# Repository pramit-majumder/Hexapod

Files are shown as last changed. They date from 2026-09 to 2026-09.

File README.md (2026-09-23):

# Custom 18-DOF Hexapod Robot






A custom-built 18-DOF hexapod robot developed as an undergraduate robotics project by Pramit Majumder, Mechatronics Engineering, KIIT. The project integrates mechanical design, servo control, inverse kinematics, ROS 2, gait generation, and real-world locomotion.

The robot is being developed as a complete hardware–software robotics system, covering mechanical construction, electronics, embedded control, kinematics, trajectory generation, and physical testing.

## Project Status

The project is currently under development. Mechanical assembly, servo and electronics testing, ROS 2 control architecture, inverse kinematics, and gait generation are being developed in parallel. Full-body locomotion testing is planned after the mechanical, electrical, and control subsystems have been validated.

## Robot Overview

The robot has six independently controlled legs. Each leg contains three actuated joints:

- Coxa.
- Femur.
- Tibia.

The total number of degrees of freedom is:

\[
6\text{ legs} \times 3\text{ DOF per leg}=18\text{ DOF}
\]

Each leg is modeled as a 3-DOF serial manipulator, allowing the foot position to be controlled in three-dimensional space.

### Approximate Leg Dimensions

| Link | Length |
|---|---:|
| Coxa | 50 mm |
| Femur | 75 mm |
| Tibia | 112 mm |

The approximate coxa–femur–tibia proportion is 0.67:1:1.5.

## Hardware

### Actuation

- 18 × MG995 servo motors.
- Three servo motors per leg.
- PCA9685 PWM servo drivers.

### Main Controllers

- Arduino Mega for low-level servo control.
- Raspberry Pi 4B for higher-level computation and robot control.

### Additional Hardware

- Custom and 3D-printed ABS structural components.
- Hexagonal top and base plates.
- Bearings for selected joints.
- M3 and M4 mechanical fasteners.
- External servo power supply.
- ESP32-CAM for future perception and scouting functionality.

The servo power system is electrically separated from the logic and control electronics. A common ground must be maintained between the servo supply, PCA9685 boards, Arduino, and communication interface.

## Software Architecture

The software stack is divided into high-level computation and low-level actuation layers:

```text
                         ROS 2
                           |
              +------------+------------+
              |                         |
       Waypoint Generator              IK
              |                         |
              +------------+------------+
                           |
                      Leg Control
                           |
                    Serial / MCU Link
                           |
                    Arduino Mega
                           |
                         I2C
                           |
                       PCA9685
                           |
                    18 Servo Motors
```

High-level motion commands are separated from the low-level servo implementation. This allows the kinematics, gait, and planning layers to operate using Cartesian or joint-space commands without depending directly on the servo driver implementation.

## ROS 2 Packages

### `hexapod_interfaces`

Custom ROS 2 interfaces used for communication among the robot's software components.

#### `Coordinates`

Represents a desired Cartesian foot position and the associated leg geometry:

```text
int64 x
int64 y
int64 z

int64 coxa_length
int64 femur_length
int64 tibia_length

float32 coxa
float32 femur
float32 tibia
```

The coordinate and geometry fields may be refactored into separate messages as the interface matures, so that input geometry and calculated joint angles are represented more clearly.

#### `LegActuators`

Transmits calculated joint actuator positions to the low-level controller. The message is intended to carry mapped actuator commands after servo offsets, direction inversions, and leg-specific calibration have been applied.

### `leg_control`

The `leg_control` node converts joint commands into actuator commands and communicates with the microcontroller through a serial connection.

### `waypoint_generator`

The waypoint-generation node produces discrete Cartesian foot positions for individual legs and coordinated gait execution.

## Communication Architecture

The robot uses a layered communication system:

- Serial communication for the Raspberry Pi–Arduino control link.
- I2C communication between the Arduino and PCA9685 PWM drivers.
- PWM signals from the PCA9685 boards to the servo motors.

The communication layer should include command validation, timeout handling, range checks, and a safe output state when the connection is interrupted.

## Motion Pipeline

The intended motion pipeline is:

```text
Desired Motion
      |
      v
Waypoints
      |
      v
Foot Coordinates
      |
      v
Inverse Kinematics
      |
      v
Joint Angles
      |
      v
Servo Mapping
      |
      v
Servo Commands
      |
      v
Physical Robot
```

## Kinematics

Each leg is modeled as a 3-DOF serial manipulator consisting of:

- Coxa joint.
- Femur joint.
- Tibia joint.

The inverse kinematics (IK) system calculates the three joint angles required to place the foot at a desired Cartesian position:

\[
P=(x,y,z)
\]

where \(x\), \(y\), and \(z\) represent the desired foot position relative to the leg coordinate frame.

The coxa joint primarily rotates the leg about the vertical axis, while the femur and tibia joints control the foot position in the resulting vertical plane.

### Leg Parameters

The current physical leg dimensions are:

\[
L_c=50\text{ mm},\qquad L_f=75\text{ mm},\qquad L_t=112\text{ mm}
\]

where:

- \(L_c\) is the coxa length.
- \(L_f\) is the femur length.
- \(L_t\) is the tibia length.

The equations below assume a defined leg coordinate convention in which the coxa angle is measured using `atan2(y, x)`, and the femur–tibia plane uses the reduced horizontal distance and signed vertical coordinate. Servo mounting conventions may require angle offsets, sign changes, or alternate elbow configurations.

### Coxa Angle

The coxa joint determines the horizontal rotation of the leg around the vertical axis:

\[
\boxed{\theta_c=\operatorname{atan2}(y,x)}
\]

### Horizontal Distance

The horizontal distance from the coxa joint to the foot is:

\[
r=\sqrt{x^2+y^2}
\]

After removing the coxa link length, the effective horizontal distance for the femur–tibia plane is:

\[
\boxed{r'=r-L_c}
\]

or, equivalently:

\[
\boxed{r'=\sqrt{x^2+y^2}-L_c}
\]

### Femur–Tibia Distance

The distance between the femur joint and the desired foot position is:

\[
\boxed{D=\sqrt{r'^2+z^2}}
\]

### Tibia Angle

Using the law of cosines, the internal femur–tibia angle is:

\[
\boxed{\theta_t=\cos^{-1}\left(\frac{L_f^2+L_t^2-D^2}{2L_fL_t}\right)}
\]

The servo command for the tibia is obtained from this geometric angle using the selected physical mounting convention. For example, an actuated knee may require \(\pi-\theta_t\), a sign inversion, or an offset.

### Femur Angle

First, calculate the angle between the horizontal axis and the line connecting the femur joint to the foot:

\[
\alpha=\operatorname{atan2}(z,r')
\]

The internal angle between the femur link and the line connecting the femur joint to the foot is:

\[
\beta=\cos^{-1}\left(\frac{L_f^2+D^2-L_t^2}{2L_fD}\right)
\]

For the selected branch of the IK solution, the femur angle is:

\[
\boxed{\theta_f=\operatorname{atan2}(z,r')+\cos^{-1}\left(\frac{L_f^2+D^2-L_t^2}{2L_fD}\right)}
\]

The alternate elbow configuration can be obtained by changing the sign of the triangle term. The final branch must be selected according to the physical leg geometry, desired posture, joint limits, and collision constraints.

### Complete IK Formulation

The complete inverse kinematics calculation is summarized as:

\[
\boxed{\theta_c=\operatorname{atan2}(y,x)}
\]

\[
\boxed{r'=\sqrt{x^2+y^2}-L_c}
\]

\[
\boxed{D=\sqrt{r'^2+z^2}}
\]

\[
\boxed{\theta_t=\cos^{-1}\left(\frac{L_f^2+L_t^2-D^2}{2L_fL_t}\right)}
\]

\[
\boxed{\theta_f=\operatorname{atan2}(z,r')+\cos^{-1}\left(\frac{L_f^2+D^2-L_t^2}{2L_fD}\right)}
\]

The resulting geometric joint-angle vector is:

\[
\boxed{(\theta_c,\theta_f,\theta_t)}
\]

These geometric angles are subsequently converted into servo commands. Servo offsets, direction inversions, left/right leg mirroring, calibration limits, and mounting orientation are handled separately according to the physical configuration of each leg.

Before evaluating the inverse trigonometric functions in software, the cosine arguments should be clamped to the interval \([-1,1]\) to protect against floating-point rounding errors.

### Reachability

A requested foot position is reachable only when the femur–tibia distance satisfies:

\[
\boxed{|L_f-L_t|\le D\le L_f+L_t}
\]

For the current leg dimensions:

\[
\boxed{37\text{ mm}\le D\le187\text{ mm}}
\]

Positions outside this workspace cannot be reached by the femur–tibia pair using the current link geometry. In practice, the usable workspace is smaller because of servo limits, mechanical interference, structural deflection, cable routing, and collision avoidance.

The geometric reachability check should be performed before calculating the inverse trigonometric terms. A complete implementation should also check the coxa angle range, femur and tibia servo limits, and whether the resulting configuration causes self-collision or ground contact.

### Coordinate-to-Actuator Pipeline

```text
Desired Foot Position
          |
          v
       (x, y, z)
          |
          v
  Reachability and Limits Check
          |
          v
    Inverse Kinematics
          |
          +----> Coxa Angle
          |
          +----> Femur Angle
          |
          +----> Tibia Angle
          |
          v
  Servo Mapping / Calibration
          |
          v
    PCA9685 PWM Commands
          |
          v
        Servos
```

## Motion Generation

The robot is intended to support both individual leg motion and coordinated six-leg locomotion. Development proceeds through the following stages:

1. Individual servo testing.
2. Individual leg movement.
3. Full-leg synchronization.
4. Cartesian foot positioning.
5. Waypoint generation.
6. Gait generation.
7. Coordinated leg movement.
8. Full-body locomotion testing.

The project distinguishes between point-to-point movement and continuous trajectories. Point-to-point motion commands a leg or joint between defined positions, whereas trajectory-based motion generates intermediate states over time to provide smoother motion and better control of velocity and acceleration.

## Gait Development

The gait system will coordinate:

- Leg lifting.
- Foot placement.
- Swing and stance phases.
- Body support.
- Foot trajectories.
- Inter-leg timing.
- Stability during weight transfer.

The gait generator will provide target foot positions to the inverse kinematics layer rather than directly commanding servo motors.

```text
Gait Generator
      |
      v
Foot Trajectory
      |
      v
Cartesian Coordinates
      |
      v
Inverse Kinematics
      |
      v
Joint Angles
      |
      v
Servo Controller
```

## Mechanical Design

The mechanical structure is designed and fabricated using 3D-printed components. Current printed parts use ABS filament with approximately 15% infill.

The mechanical design prioritizes:

- Low mass.
- Sufficient joint strength.
- Simple assembly.
- Replaceable components.
- Accessible electronics.
- Practical servo mounting.

Bearings are used at selected mechanical joints to reduce friction and mechanical loading. Final structural validation should account for servo torque, impact loads, printed-part anisotropy, fastener pull-out, and deflection under static and dynamic conditions.

## Electronics

The basic servo-control architecture is:

```text
ROS 2 / Raspberry Pi
          |
        Serial
          |
    Arduino Mega
          |
          I2C
          |
       PCA9685
          |
    18 Servo Motors
```

The PCA9685 provides dedicated PWM channels, allowing the Arduino to control the robot's servos without requiring one hardware PWM output per servo. The Arduino handles low-level timing and actuator commands, while the Raspberry Pi performs higher-level computation, kinematics, waypoint generation, and gait control.

The power system should be designed for the high instantaneous current demand of 18 MG995 servos. Logic power and servo power should use appropriate regulation, wiring, fusing, connectors, and a common ground. Emergency stop and staged power-up procedures are recommended during testing.

## Development Environment

### Robotics

- ROS 2.
- Ubuntu 22.04.
- Python.
- C++.
- Arduino.
- Raspberry Pi.

The project focuses on direct physical robot development, embedded control, ROS 2 integration, and hardware validation.

## Planned Learning-Based Control

A future direction is the investigation of neural-network-based robot control. Potential applications include:

- Neural-network inverse kinematics.
- Learned foot-position mapping.
- Reinforcement-learning-based gait generation.
- Sim-to-real policy transfer.

The learning-based controller is intended to complement, rather than replace, the conventional robot model and control pipeline. Analytical kinematics, joint limits, safety checks, and low-level actuator protections should remain available as a reliable baseline and safety layer.

## Development Roadmap

1. Design the hexapod structure.
2. Design the individual leg geometry.
3. Manufacture the initial mechanical components.
4. Assemble and validate one leg.
5. Test individual servos.
6. Establish PCA9685 servo control.
7. Complete the mechanical assembly.
8. Complete and validate the power system.
9. Finalize the top plate.
10. Test all 18 actuators.
11. Implement and validate inverse kinematics.
12. Implement waypoint generation.
13. Research and select a gait.
14. Implement gait generation.
15. Test coordinated leg movement.
16. Test complete robot locomotion.
17. Develop a learning-based controller.
18. Investigate sim-to-real transfer.

## Repository Structure

```text
hexapod/
├── README.md
├── ros2_ws/
│   └── src/
│       ├── hexapod_interfaces/
│       ├── leg_control/
│       └── waypoint_generator/
├── firmware/
│   └── arduino/
├── kinematics/
├── gait/
├── CAD/
├── documentation/
└── tests/
```

The repository structure may change as the project develops.

## Project Goals

The primary goal is to develop a complete custom hexapod platform rather than simply assemble a commercially available robot. The project combines:

- Mechanical design.
- Embedded systems.
- Robotics control.
- Forward and inverse kinematics.
- Motion planning.
- Gait generation.
- ROS 2 integration.
- Computer vision.
- Machine learning.

The final system is intended to provide a platform for experimenting with conventional and learning-based approaches to legged robotics.

## License

The project is intended to be released under the MIT License. The license status should be finalized when the repository is published.

## Author

**Pramit Majumder**  
Mechatronics Engineering  
KIIT  
Undergraduate Robotics Project

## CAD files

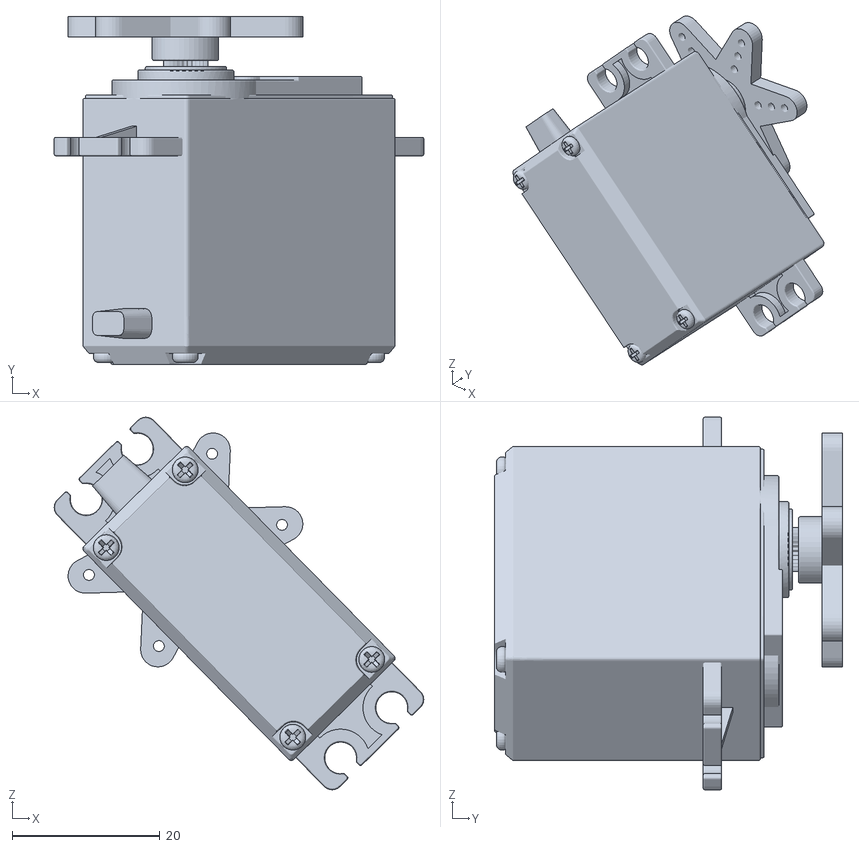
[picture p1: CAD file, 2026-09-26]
physical_hexapod_description/meshes/MG996R_Motor__5__1.stl
50.0 x 47.1 x 50.4

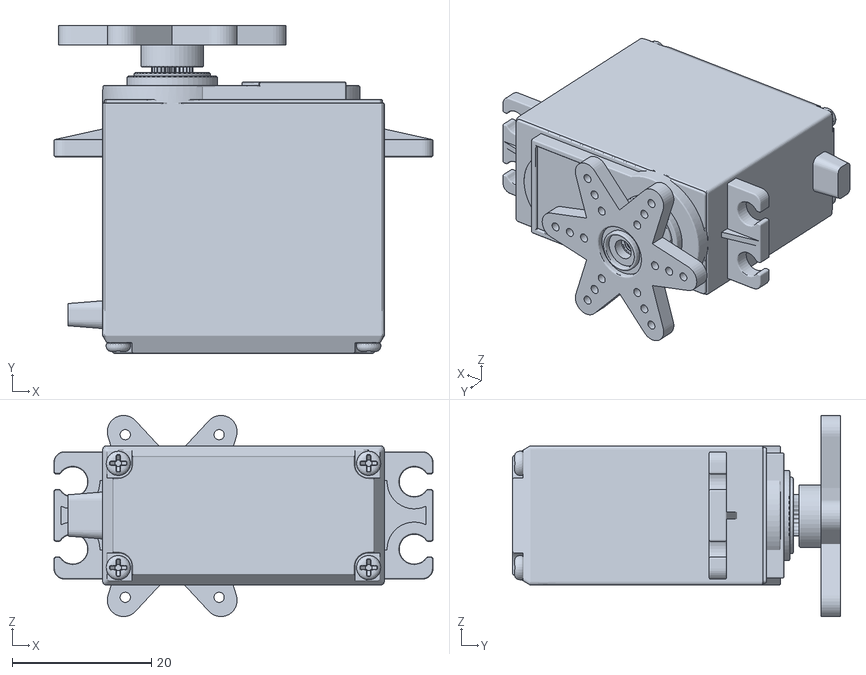
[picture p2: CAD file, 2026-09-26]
physical_hexapod_description/meshes/MG996R_Motor__3___5__1.stl
54.5 x 47.1 x 28.9

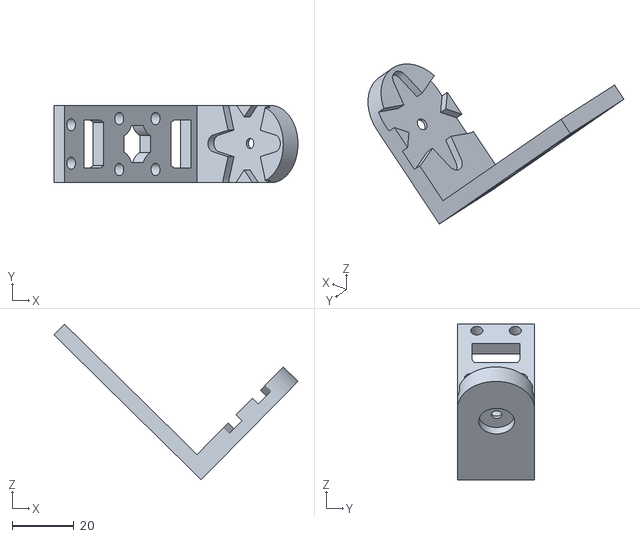
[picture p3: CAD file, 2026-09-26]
physical_hexapod_description/meshes/Holder__4__1.stl
79.2 x 25.0 x 50.5

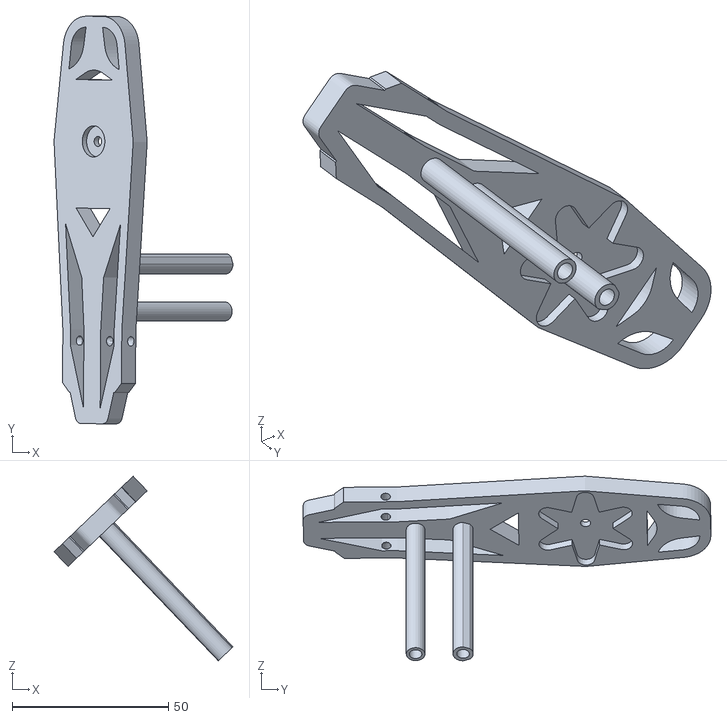
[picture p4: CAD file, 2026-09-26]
physical_hexapod_description/meshes/Tibia_Final__1.stl
57.2 x 130.3 x 59.0

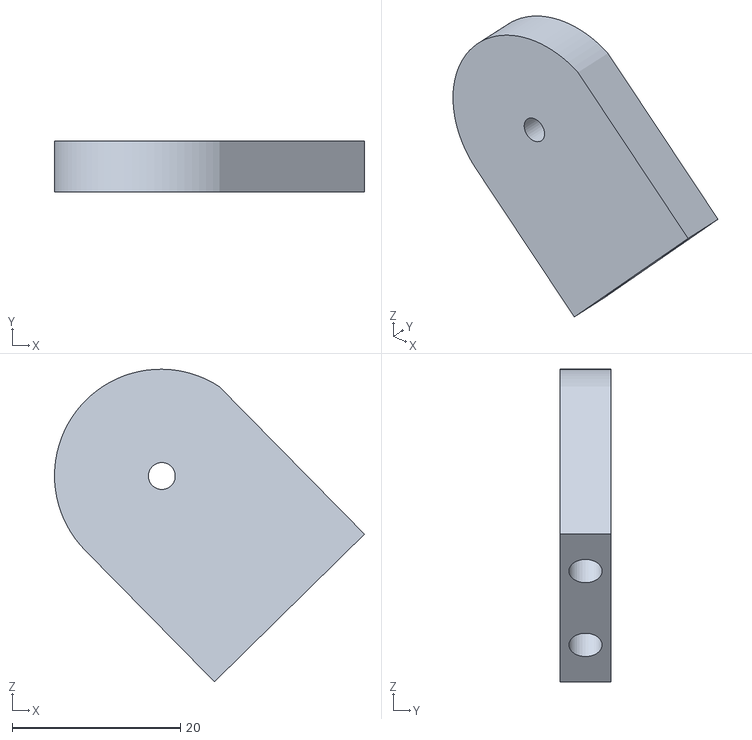
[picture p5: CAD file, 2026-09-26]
physical_hexapod_description/meshes/Bearing_Holder__2__1.stl
36.8 x 6.00 x 37.1

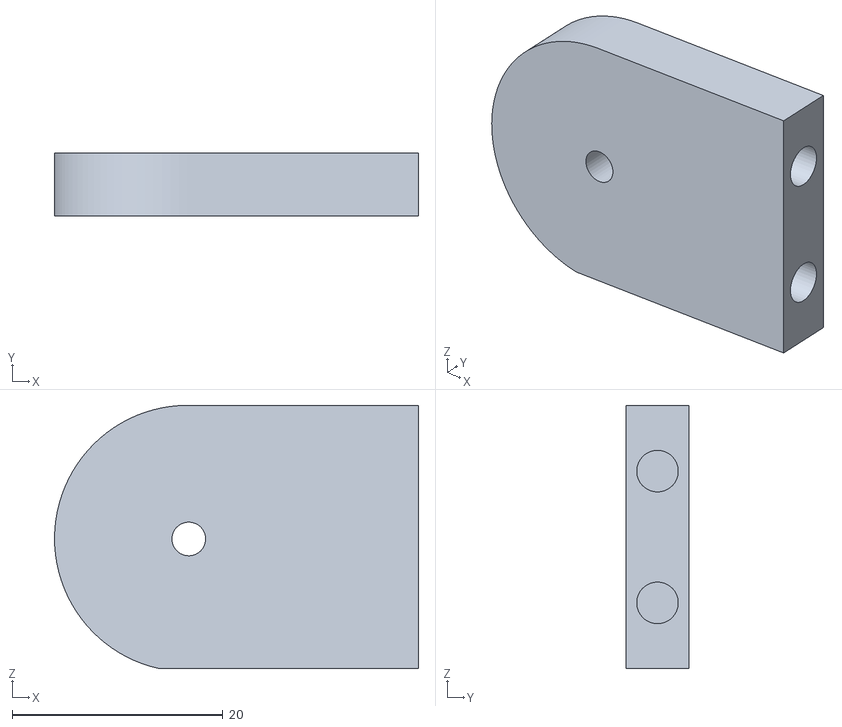
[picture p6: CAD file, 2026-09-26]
physical_hexapod_description/meshes/Bearing_Holder__5__1.stl
34.6 x 6.00 x 25.0

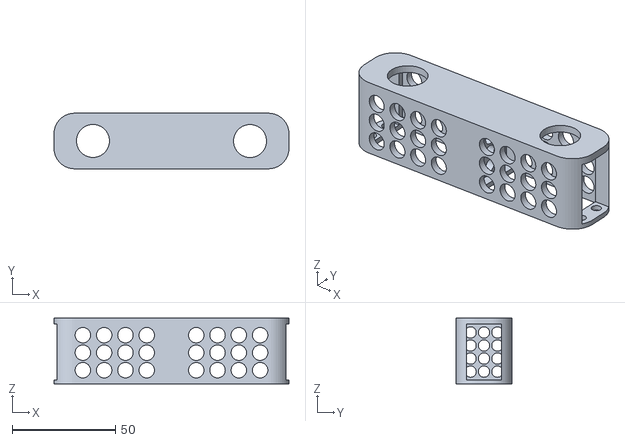
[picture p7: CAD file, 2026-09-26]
physical_hexapod_description/meshes/Femur__4__1.stl
114.0 x 27.0 x 32.0

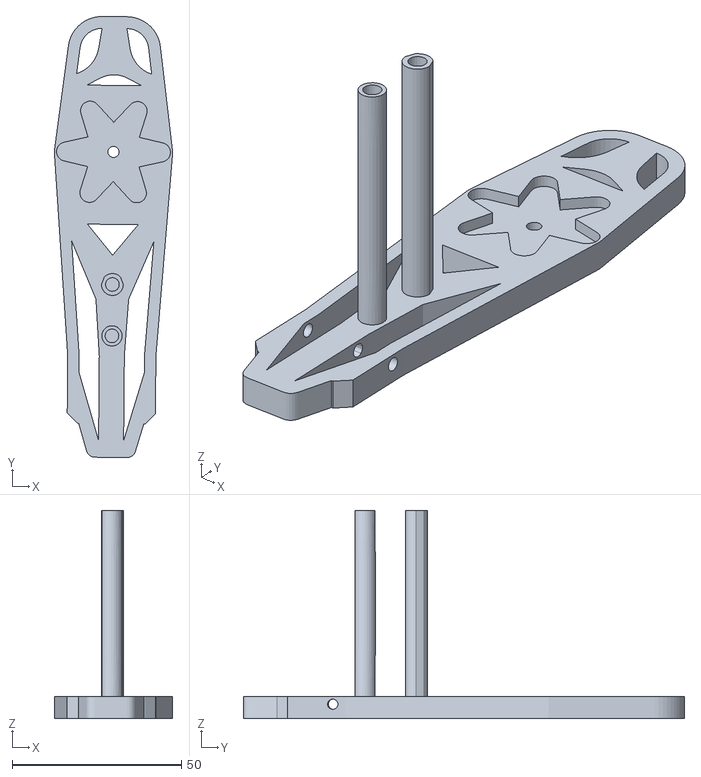
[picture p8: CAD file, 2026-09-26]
physical_hexapod_description/meshes/Tibia_Final___4__1.stl
35.0 x 130.3 x 61.5

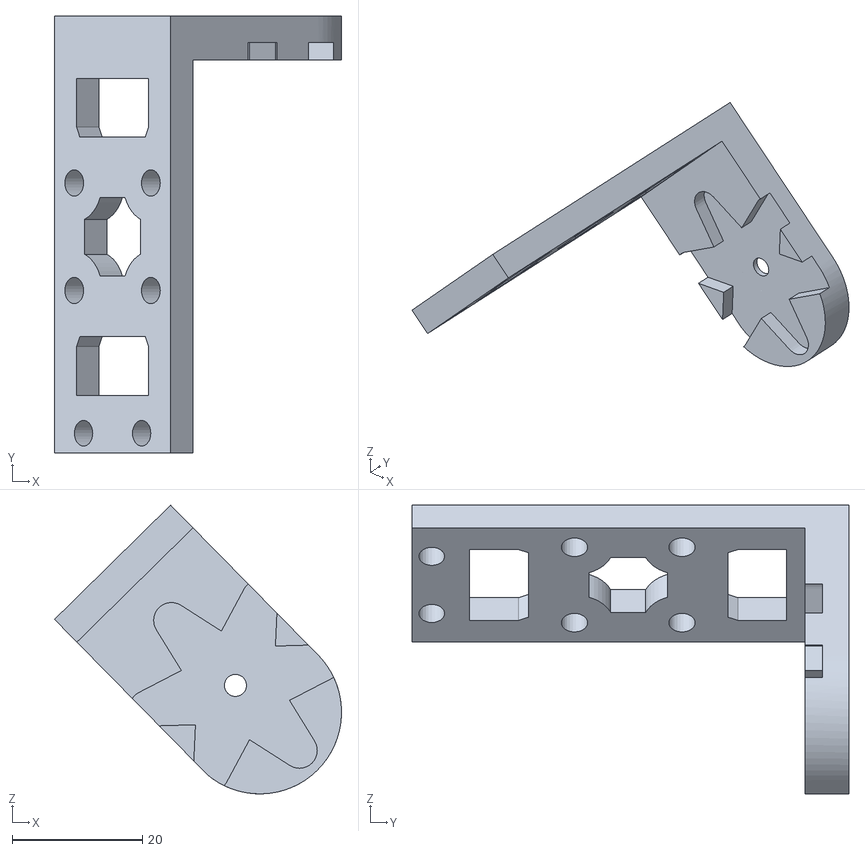
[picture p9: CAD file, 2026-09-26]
physical_hexapod_description/meshes/Holder__3__1.stl
44.0 x 67.0 x 44.3

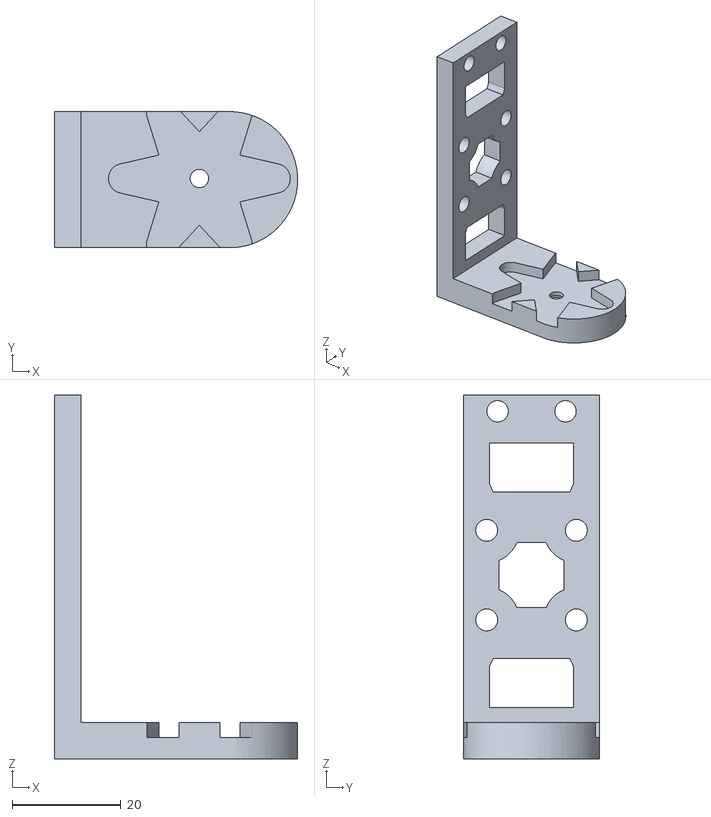
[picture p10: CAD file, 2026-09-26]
physical_hexapod_description/meshes/Holder__5__1.stl
44.8 x 25.0 x 67.0

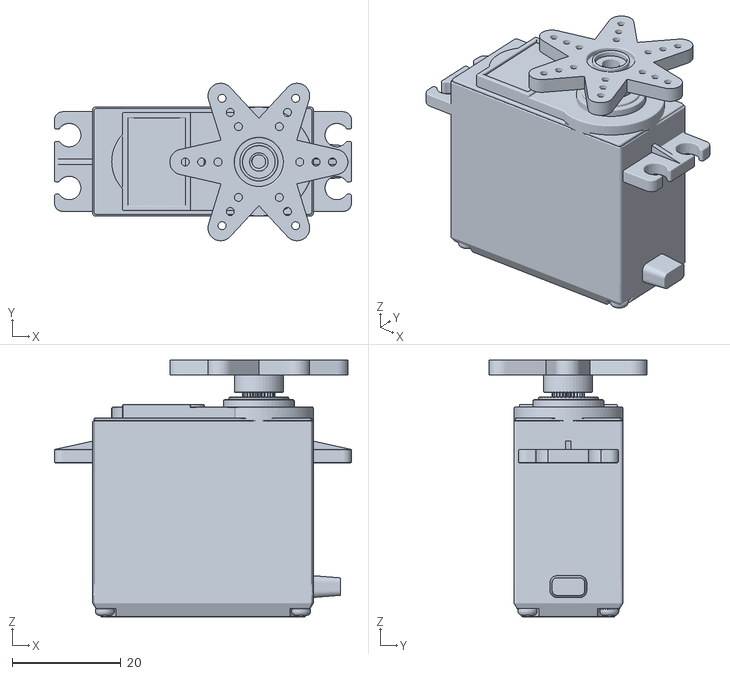
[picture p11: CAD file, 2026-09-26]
physical_hexapod_description/meshes/MG996R_Motor__1___5__1.stl
54.5 x 28.9 x 47.1

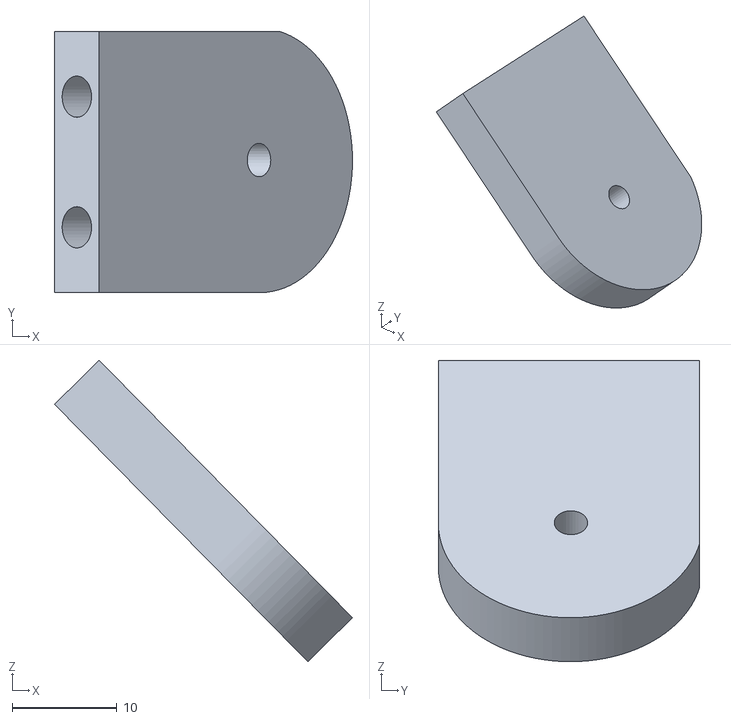
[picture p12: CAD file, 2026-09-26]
physical_hexapod_description/meshes/Bearing_Holder__1___1__1.stl
28.5 x 25.0 x 28.8

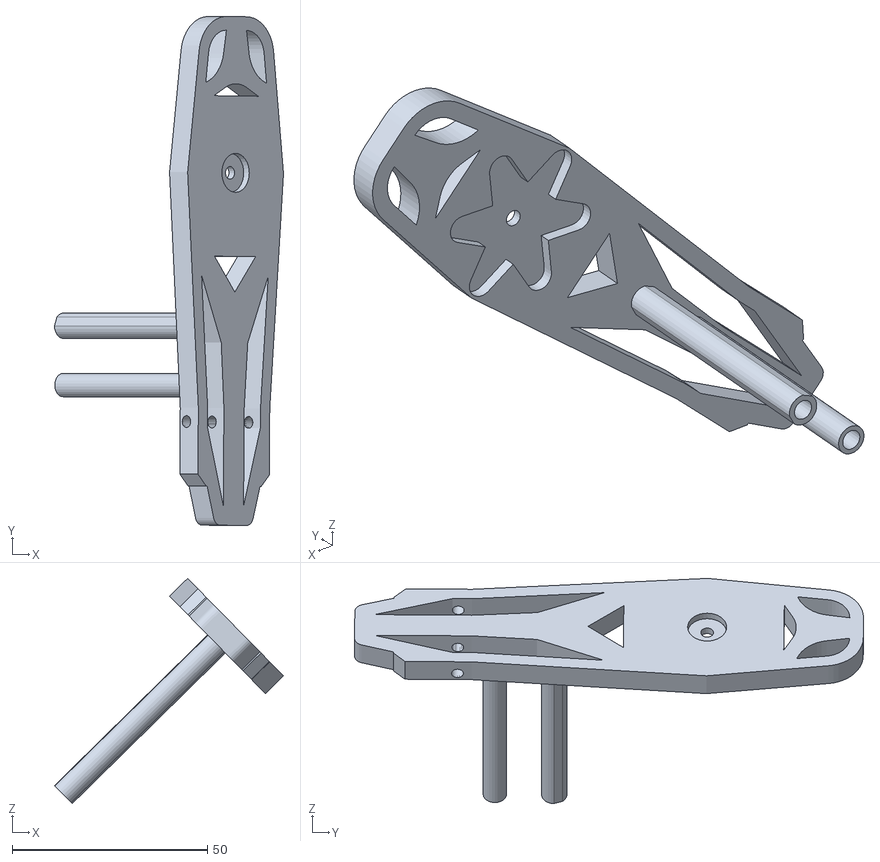
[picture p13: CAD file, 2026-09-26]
physical_hexapod_description/meshes/Tibia_Final___2__1.stl
58.6 x 130.3 x 57.7

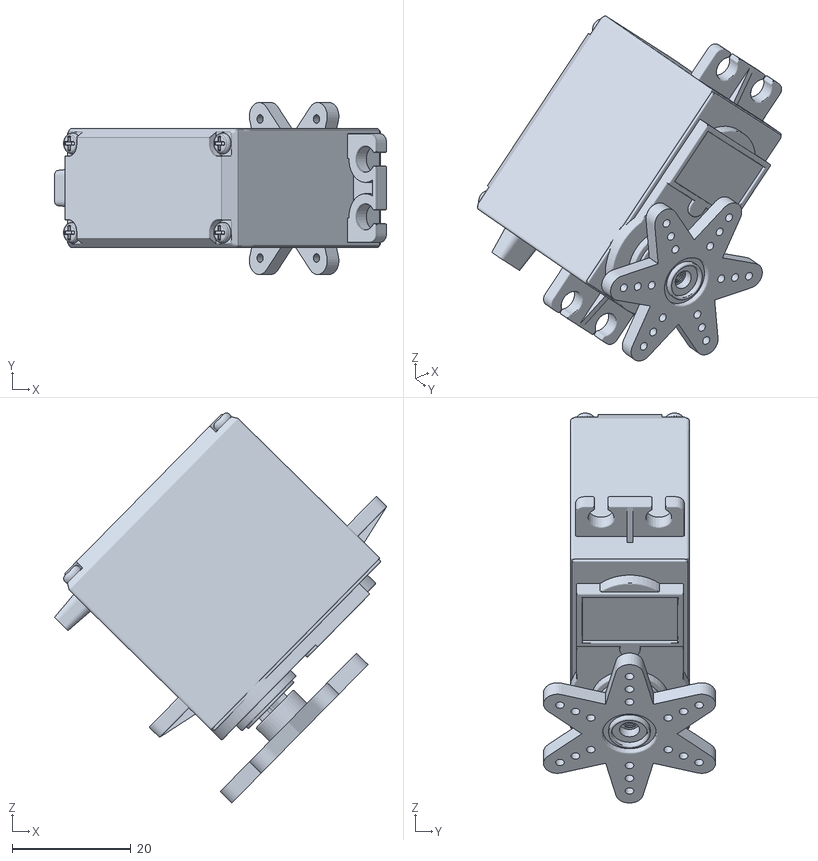
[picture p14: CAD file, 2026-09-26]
physical_hexapod_description/meshes/MG996R_Motor__1___3__1.stl
55.8 x 28.9 x 65.6

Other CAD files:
physical_hexapod_description/meshes/Bearing_Holder_1.stl
physical_hexapod_description/meshes/Femur__5__1.stl
physical_hexapod_description/meshes/MG996R_Motor_1.stl
physical_hexapod_description/meshes/Tibia_Final___3__1.stl
physical_hexapod_description/meshes/Bearing_Holder__1__1.stl
physical_hexapod_description/meshes/Bearing_Holder__1___2__1.stl
physical_hexapod_description/meshes/Bearing_Holder__1___3__1.stl
physical_hexapod_description/meshes/Bearing_Holder__1___4__1.stl
physical_hexapod_description/meshes/Bearing_Holder__1___5__1.stl
physical_hexapod_description/meshes/Bearing_Holder__3__1.stl
physical_hexapod_description/meshes/Bearing_Holder__4__1.stl
physical_hexapod_description/meshes/Bearing_Holder__6__1.stl
physical_hexapod_description/meshes/CoxaServo_1.stl
physical_hexapod_description/meshes/CoxaServo__1__1.stl
physical_hexapod_description/meshes/CoxaServo__2__1.stl
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

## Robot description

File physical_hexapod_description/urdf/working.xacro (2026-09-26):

<?xml version="1.0" ?>
<robot name="physical_hexapod" xmlns:xacro="http://www.ros.org/wiki/xacro">

<xacro:include filename="$(find physical_hexapod_description)/urdf/materials.xacro" />
<xacro:include filename="$(find physical_hexapod_description)/urdf/physical_hexapod.trans" />
<xacro:include filename="$(find physical_hexapod_description)/urdf/physical_hexapod.gazebo" />
<link name="base_link">
  <inertial>
    <origin xyz="-0.01959153923077635 -0.0073541963517954455 0.004828217632482431" rpy="0 0 0"/>
    <mass value="0.1475809399441347"/>
    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
  </inertial>
  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
</link>

<link name="CoxaServo_1">
  <inertial>
    <origin xyz="-0.022513332321356744 -0.012663831208089036 -0.015397869399309622" rpy="0 0 0"/>
    <mass value="0.10804632454892661"/>
    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
  </inertial>
  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
</link>

<link name="MG996R_Motor_1">
  <inertial>
    <origin xyz="0.020236151941974603 -0.007698893617997832 0.013646337880529824" rpy="0 0 0"/>
    <mass value="0.2527678180659355"/>
    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
  </inertial>
  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
</link>

<link name="Holder__1__1">
  <inertial>
    <origin xyz="-0.027250766281048625 -0.0112547547595295 0.1250191060400646" rpy="0 0 0"/>
    <mass value="0.08208392786171566"/>
    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
  </inertial>
  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
</link>

<link name="Holder_1">
  <inertial>
    <origin xyz="-0.012125301979133307 0.008231174587384297 -0.0034857255885452215" rpy="0 0 0"/>
    <mass value="0.08208392786171564"/>
    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
  </inertial>
  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
</link>

<link name="Bearing_Holder_1">
  <inertial>
    <origin xyz="0.007704371922184275 -4.855567701522734e-07 0.01605524288896444" rpy="0 0 0"/>
    <mass value="0.03507511571471899"/>
    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
  </inertial>
  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
</link>

<link name="Bearing_Holder__1__1">
  <inertial>
    <origin xyz="-0.012047353057940913 0.006287748273405135 -0.01150935391181987" rpy="0 0 0"/>
    <mass value="0.03507511571471899"/>
    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
  </inertial>
  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
</link>

<link name="MG996R_Motor__3__1">
  <inertial>
    <origin xyz="0.02969436147498436 -0.0060846115242419235 0.1948052067310069" rpy="0 0 0"/>
    <mass value="0.2527678180659355"/>
    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
  </inertial>
  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
</link>

<link name="Femur_1">
  <inertial>
    <origin xyz="-0.02473141214941163 0.004669975866199815 -0.050033397948334196" rpy="0 0 0"/>
    <mass value="0.18517326458962144"/>
    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
  </inertial>
  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
</link>

<link name="MG996R_Motor__1__1">
  <inertial>
    <origin xyz="0.022614741205250782 0.00485314778936443 0.010956371732594894" rpy="0 0 0"/>
    <mass value="0.2527678180659355"/>
    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
  </inertial>
  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
</link>

<link name="Triangle_1">
  <inertial>
    <origin xyz="0.023495893839868554 -0.007808520493486633 -0.018653607404226474" rpy="0 0 0"/>
    <mass value="0.11021612920690807"/>
    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
  </inertial>
  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
</link>

<link name="Tibia_LSide_Final__1">
  <inertial>
    <origin xyz="-0.0017126560365198495 0.045291009751985634 -0.0029729026942214576" rpy="0 0 0"/>
    <mass value="0.14990505403636886"/>
    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
  </inertial>
  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
</link>

<link name="Tibia_Final__1">
  <inertial>
    <origin xyz="0.0020794885211026792 -0.024142922595412723 -0.0024957185081625755" rpy="0 0 0"/>
    <mass value="0.1628974192594201"/>
    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
  </inertial>
  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
</link>

<link name="CoxaServo__1__1">
  <inertial>
    <origin xyz="0.015031340402115165 -0.012663831208089064 -0.022759395411806743" rpy="0 0 0"/>
    <mass value="0.10804632454892661"/>
    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
  </inertial>
  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
</link>

<link name="MG996R_Motor__4__1">
  <inertial>
    <origin xyz="-0.020231945874321103 -0.007898893617997895 0.01365155000345196" rpy="0 0 0"/>
    <mass value="0.2527678180659355"/>
    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
  </inertial>
  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
</link>

<link name="Holder__1___1__1">
  <inertial>
    <origin xyz="0.011035784575921262 -0.015746754759529916 -0.01092127879531532" rpy="0 0 0"/>
    <mass value="0.08208392786171566"/>
    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
  </inertial>
  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
</link>

<link name="Bearing_Holder__2__1">
  <inertial>
    <origin xyz="-0.007204304463187733 -4.855567706865682e-07 0.016285993521385655" rpy="0 0 0"/>
    <mass value="0.03507511571471899"/>
    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
  </inertial>
  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
</link>

<link name="Bearing_Holder__1___1__1">
  <inertial>
    <origin xyz="0.011685550377638632 -0.006212251726592695 -0.011876477703747446" rpy="0 0 0"/>
    <mass value="0.03507511571471899"/>
    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
  </inertial>
  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
</link>

<link name="Holder__2__1">
  <inertial>
    <origin xyz="-0.008096962153329432 0.008231174587384114 -0.02364476064094448" rpy="0 0 0"/>
    <mass value="0.08208392786171564"/>
    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
  </inertial>
  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
</link>

<link name="MG996R_Motor__3___1__1">
  <inertial>
    <origin xyz="0.024958976274668046 7.438847575781844e-05 0.011061798315041144" rpy="0 0 0"/>
    <mass value="0.2527678180659355"/>
    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
  </inertial>
  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
</link>

<link name="Femur__1__1">
  <inertial>
    <origin xyz="0.05039359654514279 -0.004983439601077954 -0.023988504416483675" rpy="0 0 0"/>
    <mass value="0.18517326458962144"/>
    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
  </inertial>
  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
</link>

<link name="MG996R_Motor__1___1__1">
  <inertial>
    <origin xyz="-0.011289317108707259 0.004852732322045017 0.022450141830220954" rpy="0 0 0"/>
    <mass value="0.2527678180659355"/>
    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
  </inertial>
  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
</link>

<link name="Tibia_wtf_1_1">
  <inertial>
    <origin xyz="0.002464655533831267 -0.024143338062732212 0.0021164331105320566" rpy="0 0 0"/>
    <mass value="0.1628974192594201"/>
    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
  </inertial>
  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
</link>

<link name="CoxaServo__2__1">
  <inertial>
    <origin xyz="-0.022515846620965035 -0.012663831208089667 0.01539532154428086" rpy="0 0 0"/>
    <mass value="0.10804632454892661"/>
    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
  </inertial>
  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
</link>

<link name="MG996R_Motor__5__1">
  <inertial>
    <origin xyz="0.020232439655471224 -0.007698893617998456 -0.013651623870977778" rpy="0 0 0"/>
    <mass value="0.2527678180659355"/>
    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
  </inertial>
  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
</link>

<link name="Holder__3__1">
  <inertial>
    <origin xyz="-0.011035290794771321 -0.01574675475952898 0.01092120492778953" rpy="0 0 0"/>
    <mass value="0.08208392786171564"/>
    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
  </inertial>
  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
</link>

<link name="Bearing_Holder__1___2__1">
  <inertial>
    <origin xyz="0.007203798244337006 -4.855567659022009e-07 -0.01628606738890942" rpy="0 0 0"/>
    <mass value="0.03507511571471899"/>
    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
  </inertial>
  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
</link>

<link name="Holder__1___2__1">
  <inertial>
    <origin xyz="-0.003664544065519401 -0.008268825412614133 0.012071686773418355" rpy="0 0 0"/>
    <mass value="0.08208392786171566"/>
    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
  </inertial>
  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
</link>

<link name="Femur__2__1">
  <inertial>
    <origin xyz="-0.04896874528828135 -0.0049834396011195605 0.0253920739346917" rpy="0 0 0"/>
    <mass value="0.18517326458962144"/>
    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
  </inertial>
  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
</link>

<link name="MG996R_Motor__3___2__1">
  <inertial>
    <origin xyz="0.011146608774642991 -0.004846852210636634 -0.022590846197805686" rpy="0 0 0"/>
    <mass value="0.2527678180659355"/>
    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
  </inertial>
  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
</link>

<link name="Tibia_Final___2__1">
  <inertial>
    <origin xyz="-0.002465363867895254 -0.024142922595413913 -0.002116137478117508" rpy="0 0 0"/>
    <mass value="0.1628974192594201"/>
    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
  </inertial>
  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
</link>

<link name="Triangle__2__1">
  <inertial>
    <origin xyz="-0.01839762653609814 -0.007704274658385614 -0.023852205058753545" rpy="0 0 0"/>
    <mass value="0.11021612920690807"/>
    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
  </inertial>
  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
</link>

<link name="Tibia_LSide_Final___2__1">
  <inertial>
    <origin xyz="-0.002320557871883233 0.020602510675193794 -0.0022830672143610287" rpy="0 0 0"/>
    <mass value="0.14990505403636886"/>
    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
  </inertial>
  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
</link>

<link name="CoxaServo__3__1">
  <inertial>
    <origin xyz="0.015028826102506686 -0.012663831208089713 0.0227617955317838" rpy="0 0 0"/>
    <mass value="0.10804632454892661"/>
    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
  </inertial>
  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
</link>

<link name="MG996R_Motor__6__1">
  <inertial>
    <origin xyz="-0.013322452804465756 -0.007898893617998524 -0.020450084718447295" rpy="0 0 0"/>
    <mass value="0.2527678180659355"/>
    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
  </inertial>
  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
</link>
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

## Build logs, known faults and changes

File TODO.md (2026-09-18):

Write all 18 dofs
Calculate the time it takes to calculate 18dofs
Use a Feed forward neural network for 18 dofs(Use PyTorch)
Read the NASA TECHNICAL DOCUMENT

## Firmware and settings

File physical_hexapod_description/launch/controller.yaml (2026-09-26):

working_controller:
  # Publish all joint states -----------------------------------
  joint_state_controller:
    type: joint_state_controller/JointStateController
    publish_rate: 50

  # Position Controllers --------------------------------------
  Revolute 104_position_controller:
    type: effort_controllers/JointPositionController
    joint: Revolute 104
    pid: {p: 100.0, i: 0.01, d: 10.0}
  Revolute 108_position_controller:
    type: effort_controllers/JointPositionController
    joint: Revolute 108
    pid: {p: 100.0, i: 0.01, d: 10.0}
  Revolute 113_position_controller:
    type: effort_controllers/JointPositionController
    joint: Revolute 113
    pid: {p: 100.0, i: 0.01, d: 10.0}
  Revolute 116_position_controller:
    type: effort_controllers/JointPositionController
    joint: Revolute 116
    pid: {p: 100.0, i: 0.01, d: 10.0}
  Revolute 120_position_controller:
    type: effort_controllers/JointPositionController
    joint: Revolute 120
    pid: {p: 100.0, i: 0.01, d: 10.0}
  Revolute 125_position_controller:
    type: effort_controllers/JointPositionController
    joint: Revolute 125
    pid: {p: 100.0, i: 0.01, d: 10.0}
  Revolute 128_position_controller:
    type: effort_controllers/JointPositionController
    joint: Revolute 128
    pid: {p: 100.0, i: 0.01, d: 10.0}
  Revolute 135_position_controller:
    type: effort_controllers/JointPositionController
    joint: Revolute 135
    pid: {p: 100.0, i: 0.01, d: 10.0}
  Revolute 140_position_controller:
    type: effort_controllers/JointPositionController
    joint: Revolute 140
    pid: {p: 100.0, i: 0.01, d: 10.0}
  Revolute 142_position_controller:
    type: effort_controllers/JointPositionController
    joint: Revolute 142
    pid: {p: 100.0, i: 0.01, d: 10.0}
  Revolute 147_position_controller:
    type: effort_controllers/JointPositionController
    joint: Revolute 147
    pid: {p: 100.0, i: 0.01, d: 10.0}
  Revolute 155_position_controller:
    type: effort_controllers/JointPositionController
    joint: Revolute 155
    pid: {p: 100.0, i: 0.01, d: 10.0}
  Revolute 158_position_controller:
    type: effort_controllers/JointPositionController
    joint: Revolute 158
    pid: {p: 100.0, i: 0.01, d: 10.0}
  Revolute 159_position_controller:
    type: effort_controllers/JointPositionController
    joint: Revolute 159
    pid: {p: 100.0, i: 0.01, d: 10.0}
  Revolute 164_position_controller:
    type: effort_controllers/JointPositionController
    joint: Revolute 164
    pid: {p: 100.0, i: 0.01, d: 10.0}
  Revolute 167_position_controller:
    type: effort_controllers/JointPositionController
    joint: Revolute 167
    pid: {p: 100.0, i: 0.01, d: 10.0}
  Revolute 171_position_controller:
    type: effort_controllers/JointPositionController
    joint: Revolute 171
    pid: {p: 100.0, i: 0.01, d: 10.0}
  Revolute 179_position_controller:
    type: effort_controllers/JointPositionController
    joint: Revolute 179
    pid: {p: 100.0, i: 0.01, d: 10.0}

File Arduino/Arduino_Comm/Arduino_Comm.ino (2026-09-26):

#include <Wire.h>

#include <Adafruit_PWMServoDriver.h>

#include <Servo.h>

Servo servo1;
Servo servo2;
Servo servo3;

Adafruit_PWMServoDriver pwm = Adafruit_PWMServoDriver(0x40);

#define SERVOMIN 150

#define SERVOMAX 600

void setServoAngle(uint8_t channel, int angle) {

  angle = constrain(angle, 0, 180);

  int pulse = map(angle, 0, 180, SERVOMIN, SERVOMAX);

  pwm.setPWM(channel, 0, pulse);

}

void setup() {
  Serial.begin(115200);

  Wire.begin();

  pwm.begin();

  pwm.setOscillatorFrequency(27000000);

  pwm.setPWMFreq(50);

  delay(500);

  while (!Serial) {}
  while (Serial.available() > 0) {
    Serial.read();
  }
  servo1.attach(9);
  servo2.attach(10);
  servo3.attach(11);

  pinMode(LED_BUILTIN, OUTPUT);
}

void loop() {
  if (Serial.available() > 0) {
    String cmd = Serial.readStringUntil('\n');
    cmd.trim();

    // Expecting format: coxa;femur;tibia  (e.g. "90;45;120")
    int firstSep  = cmd.indexOf(';');
    int secondSep = cmd.indexOf(';', firstSep + 1);

    if (firstSep == -1 || secondSep == -1) {
      // malformed line, ignore it
      return;
    }

    String coxaStr  = cmd.substring(0, firstSep);
    String femurStr = cmd.substring(firstSep + 1, secondSep);
    String tibiaStr = cmd.substring(secondSep + 1);
    digitalWrite(LED_BUILTIN, HIGH);
    int coxaVal  = constrain(coxaStr.toInt(), 0, 180);
    int femurVal = constrain(femurStr.toInt(), 0, 180);
    int tibiaVal = constrain(tibiaStr.toInt(), 0, 180);
    tibiaVal = map(tibiaVal, 0, 180, 180, 0);
 

    setServoAngle(0, coxaVal);
    setServoAngle(1, femurVal);
    setServoAngle(2, tibiaVal);

    setServoAngle(3, coxaVal);
    setServoAngle(4, femurVal);//COXA JOINT AND TIBIA HAVE BEEN SWITCHED, CHECK WITH ONLY THIS
    setServoAngle(5, tibiaVal);

    setServoAngle(6, coxaVal);
    setServoAngle(7, femurVal);
    setServoAngle(8, tibiaVal);

    setServoAngle(9, coxaVal);
    setServoAngle(10, femurVal);
    setServoAngle(11, tibiaVal);

    setServoAngle(12, coxaVal);
    setServoAngle(15, femurVal);
    setServoAngle(14, tibiaVal);

    servo1.write(coxaVal);
    servo2.write(femurVal);
    servo3.write(tibiaVal);
    
    // digitalWrite(LED_BUILTIN, LOW);
  }
}

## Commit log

2026-08-22 Timer and Communication added, Physical Verification required
2026-08-26 Physical Verification Completed with Updated Inverse Kinematics code and Interpolation at 200 samples at 0.1Hz
2026-09-21 Arduino Code
2026-09-26 Meshes Upload w URDF
    [Bearing_Holder_1.stl, Bearing_Holder__1__1.stl, Bearing_Holder__1___1__1.stl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]
2026-10-23 UPDATED MATLAB INVERSE KINEMATICS
2026-10-28 NEED TO ADD ANOTHER MOETHOD FOR THE LEG TO BE UPRIGHT OR NOT
2026-11-09 Leveler, makes all legs on the same angles, vis a vis all on the same coordinates respect to their origin on the body
2026-11-09 Leveler added, robot has no freejoint and corrected all the wrong pin numbers
2026-11-10 MATLAB Inverse Kinematics Verification
2026-11-10 Updated for physical Modelling and testing for X inverse kinematics

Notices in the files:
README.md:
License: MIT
